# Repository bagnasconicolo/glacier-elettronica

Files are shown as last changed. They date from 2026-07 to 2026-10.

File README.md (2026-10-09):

# glacier-elettronica — Rivelatore di raggi cosmici

Front-end di lettura per un **rivelatore di muoni cosmici** basato su SiPM +
scintillatore: amplificatore veloce, discriminatore a soglia regolabile,
generazione del bias del SiPM, uscita TTL e **uscita 3,3 V per Raspberry Pi**.

Ricostruzione completa in KiCad — dal solo PDF scansionato dello schema originale
INFN sez. Torino ("Riv. Cosmici 2024 — Amplif, alim, soglie", S. Gallian) —
accompagnata da simulazioni circuitali non lineari, un verificatore che gira
**direttamente dallo schema**, la **simulazione LTspice della scheda completa** e un
sito didattico interattivo.




## Come funziona il circuito

Un muone attraversa lo scintillatore e produce un lampo di luce; il **SiPM**
(AFBR-S4N22P014M, polarizzato a ~38,4 V generati a bordo) lo converte in un
impulso di corrente. Due transistor — **BFR93A** (Q1) e **MMBTH81** (Q2) —
amplificano di ~28×. Il comparatore **MAX961** confronta con la soglia impostata
dal trimmer V2 e produce l'impulso digitale **CMP_Q**; una rete C9/R16 (latch)
evita i doppi conteggi. Da qui il segnale va al driver **MCP1402** (uscita TTL su
J2) e al buffer **74LVC1G17** alimentato a 3,3 V, che lo porta sul connettore
LEMO/J4 a 0–3,3 V, pronto per un GPIO del **Raspberry Pi**. Un timer **555** accende un LED per
11 ms a ogni evento.

Rate reale su una paletta 10×10 cm a livello del mare: **~1,7 muoni/s**.

| Schema | PCB |
|---|---|
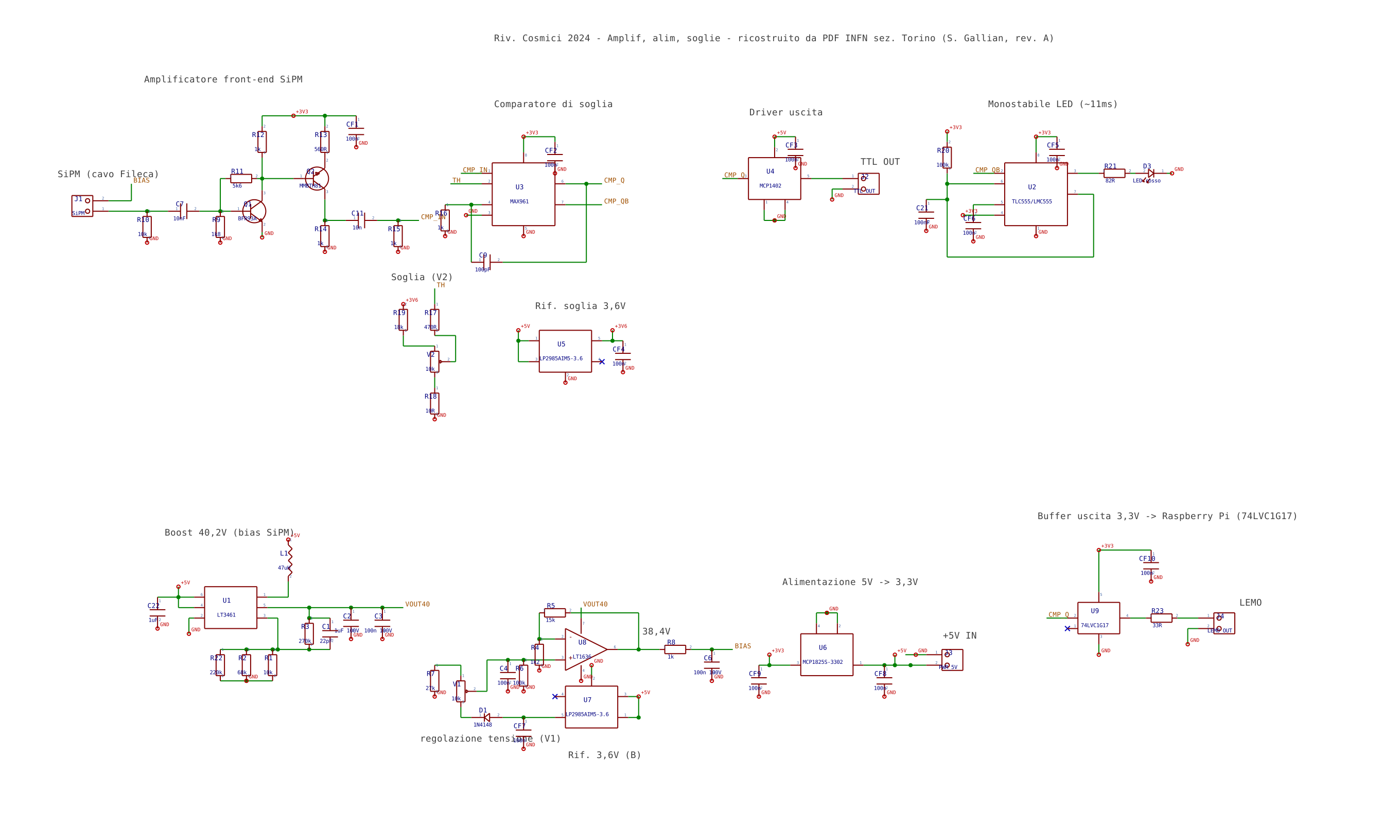
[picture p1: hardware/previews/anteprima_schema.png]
schema
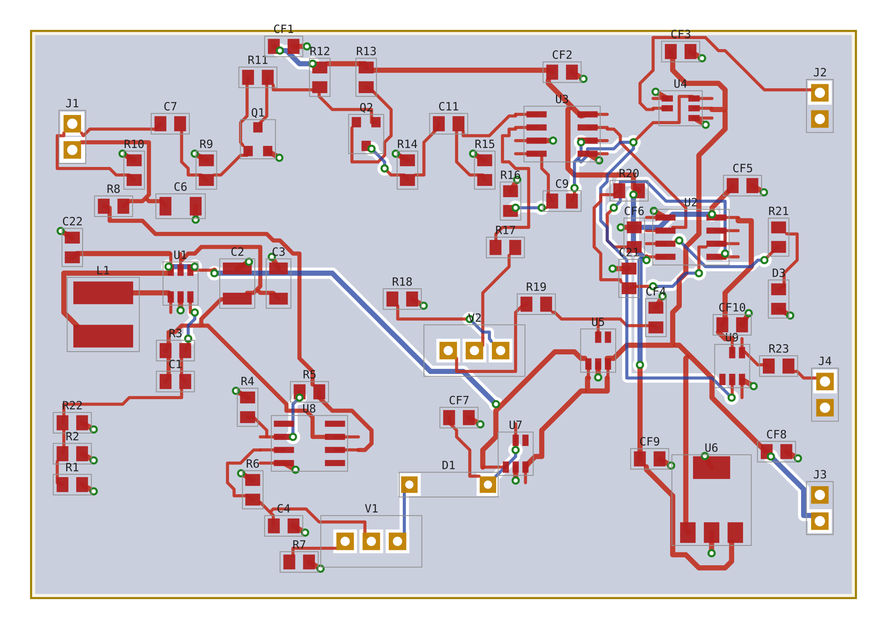
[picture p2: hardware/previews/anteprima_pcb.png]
pcb
|  |  |

## Struttura del repository

```
hardware/          progetto KiCad (schema, PCB, librerie, Gerber, BOM)
  riv_cosmici.kicad_pro/.kicad_sch/.kicad_pcb
  riv.kicad_sym, rivlib.pretty/        librerie simboli e footprint del progetto
  gerber/, riv_cosmici_gerber.zip      Gerber RS-274X + Excellon (pronti per il fab)
  bom/                                 distinta base (.xlsx e .csv) con codici Farnell/RS
  PRIMA_DI_ORDINARE.md                 cosa e' verificato e cosa decidere prima dell'ordine
  jlcpcb/                              Gerber, BOM e CPL per PCB + montaggio su JLCPCB
  variante_3ch/                        VARIANTE A 3 CANALI + coincidenza AND, uscite LEMO
  render3d/                            render 3D delle schede montate (three.js)
  previews/                            anteprime PNG
  generator/                           script Python che GENERANO lo hardware (sorgente)
simulation/        modelli circuitali non lineari + verifica dallo schema
  ltspice/             SCHEDA COMPLETA per LTspice (.asc) e ngspice (.cir) + verifica
  sim_catena.py        catena di segnale (SiPM -> ampli -> comparatore)
  sim_muoni.py         treno di muoni (Poisson + Landau) + dark count
  sim_buffer.py        (variante superata) vecchio buffer a 2 transistor
  sim_treno_completo.py (variante superata) catena fino a un Arduino a 5 V
  netlist_from_kicad.py   estrae la netlist dal .kicad_sch
  verify_from_schematic.py simula DALLA netlist estratta (front-end + uscita)
  make_recap.py        genera il PDF di recap
  riv_cosmici_frontend.cir  netlist SPICE del solo front-end (storica)
  figures/             grafici generati
web/               sito didattico interattivo (single-file, offline)
firmware/          (variante superata) sketch Arduino
docs/              schemi in PDF (1 e 3 canali), RECAP_progetto.pdf, schema_originale_INFN.pdf
```

## Due versioni

| | Scheda a 1 canale | Variante a 3 canali |
|---|---|---|
| Dove | `hardware/` | `hardware/variante_3ch/` |
| Barre / SiPM | 1 | 3 (bias e soglia regolabili per canale) |
| Uscite | LEMO/header 3,3 V + TTL 5 V | 3 LEMO 00 (canali) + 1 LEMO 00 (AND) |
| Coincidenza | — | 74LVC1G11 con jumper di esclusione |
| Test point | — | 6 per canale + 6 comuni |
| PCB | 80 × 55 mm | 103 × 215 mm, serigrafia didattica, 8 fori M3 |
| Schema PDF | `docs/schema_riv_cosmici_1canale.pdf` | `docs/schema_riv_cosmici_3canali.pdf` |

Render 3D delle schede montate: `hardware/render3d/out/1ch/` e `out/3ch/`
(rigenerabili con `python scene.py 3ch && node shoot.mjs 3ch`).

## Hardware (KiCad)

Apri `hardware/riv_cosmici.kicad_pro` con **KiCad 6 o successivo**. Le librerie di
progetto (`riv.kicad_sym`, `rivlib.pretty`) sono già referenziate da `sym-lib-table`
e `fp-lib-table` con percorso `${KIPRJMOD}`. I Gerber in `hardware/gerber/` sono
pronti per la produzione (2 layer, 80×55 mm; DRC geometrico e connettività a zero
errori). La BOM in `hardware/bom/` riporta i codici d'ordine Farnell/RS trascritti
dal progetto originale.

### Prima di ordinare

Leggi **[`hardware/PRIMA_DI_ORDINARE.md`](hardware/PRIMA_DI_ORDINARE.md)**: elenca cosa è
stato verificato (schema = originale INFN pin per pin, piedinature sui datasheet, DRC e
connettività del PCB, simulazione della scheda intera) e i punti da decidere al
montaggio, che non richiedono modifiche al PCB: R3 per restare sotto i 40 V del
LT3461, i condensatori d'uscita dei regolatori, l'ingombro di L1 e il LEMO.

Rigenerare tutto (schema, PCB, Gerber, BOM, anteprime) dal modello dati:

```bash
cd hardware/generator
python gen_sch.py && python gen_pcb.py && python gerber_out.py && python gen_bom.py
python gen_jlcpcb.py   # dopo aver aggiornato hardware/gerber e lo zip
python render_sch.py && python render_pcb.py
# schema, PCB e Gerber escono in generator/riv_cosmici/: copiarli in hardware/
```

## Simulazioni

Tutto in Python puro (nessun SPICE richiesto): un solver MNA + Newton con transistor
Ebers-Moll. Installa le dipendenze e lancia gli script da `simulation/`:

```bash
pip install -r requirements.txt
cd simulation
python sim_catena.py          # risposta della catena, punto di lavoro DC
python sim_muoni.py           # treno di muoni + dark count, reiezione
python sim_buffer.py          # buffer: CMP_Q vs TTL, storage time
python sim_treno_completo.py  # end-to-end fino al pin Arduino
```

Risultati principali (dettaglio in `simulation/RISULTATI_SIMULAZIONE.md`):
guadagno ~35 mV/fotoelettrone, saturazione oltre ~40 p.e.; soglia regolabile da
~2 mV a ~1,3 V; 7 muoni → 7 conteggi con 46 dark count rigettati; rate medio
1,68 conteggi/s a scala reale.

### Simulazione LTspice della scheda COMPLETA

In `simulation/ltspice/` c'è tutta la scheda — alimentazioni, boost 40 V, bias del SiPM,
front-end, soglia, comparatore con latch, driver TTL, 555 + LED, uscita per il
Raspberry Pi — come **schema LTspice** (`riv_cosmici_completo.asc`, si apre e si preme
Run) e come netlist (`.cir`, anche per ngspice). È generata dallo stesso modello dati
dello schema KiCad: riferimenti e nomi delle reti coincidono.

```bash
cd simulation/ltspice
python verifica_ltspice.py   # .asc == .cir, copertura KiCad, 21 controlli, grafico
```

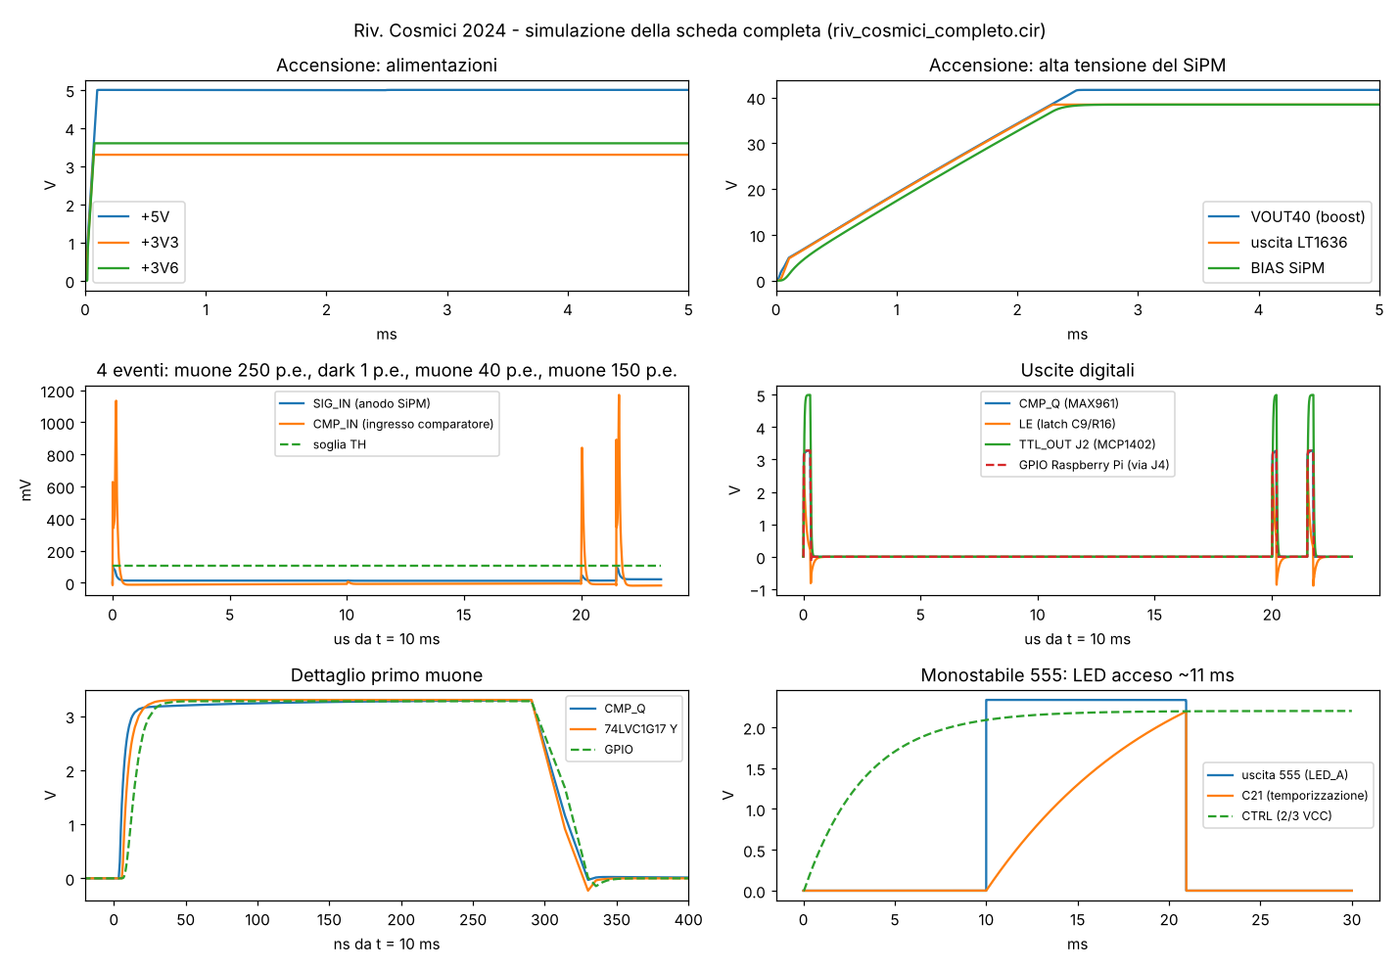
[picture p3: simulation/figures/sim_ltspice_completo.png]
simulazione completa


Dettagli, parametri e limiti dei modelli: [`simulation/ltspice/LEGGIMI.md`](simulation/ltspice/LEGGIMI.md).

### Verifica DIRETTA dallo schema

Le simulazioni normali usano una netlist trascritta a mano. Per legare la verifica
allo schema vero:

```bash
cd simulation
python verify_from_schematic.py            # front-end letto dal .kicad_sch
python verify_from_schematic.py --uscita   # + stadio d'uscita (U9 -> J4) dal .kicad_sch
```

`netlist_from_kicad.py` estrae la netlist per geometria direttamente dal file
`hardware/riv_cosmici.kicad_sch` (valori, fili, etichette, alimentazioni) e
`verify_from_schematic.py` la simula: il punto di lavoro coincide col riferimento al
millivolt, e un errore introdotto nello schema (valore o cablaggio) cambia il
risultato — così la simulazione diventa una vera verifica dello schema.

Il **PDF di recap** con tutti i grafici e i numeri si rigenera con:
`python make_recap.py` → `docs/RECAP_progetto.pdf`.

## Sito didattico

In `web/` ci sono pagine HTML autonome (funzionano offline, senza librerie
esterne), con dentro lo **stesso solver circuitale** portato in JavaScript:

- `schematico_interattivo.html` — lo schema elettrico "vivo": lancia un muone al
  rallentatore, sonde sui nodi, componenti cliccabili, trimmer della soglia
  trascinabile, oscilloscopio.
- `viaggio_del_muone.html` — la catena stadio per stadio, con i grafici ricalcolati
  in tempo reale.
- `rivelatore_cosmici.html` — cruscotto con muoni animati e conteggio.

## Lettura con Raspberry Pi

J4 pin 1 → un GPIO (es. GPIO17) con 330 Ω in serie, J4 pin 2 → GND. L'uscita è
0–3,3 V. Ogni muone dà un impulso di ≥ 84 ns: va contato **a interrupt sul fronte di
salita** (es. `libgpiod`, eventi `RISING_EDGE`), non in polling. **Non collegare J2**
(TTL a 5 V) al Pi. Lo sketch in `firmware/` è della vecchia variante Arduino a 5 V.

## Rigenerare lo hardware

Gli script in `hardware/generator/` sono il "sorgente" da cui sono stati generati
schema, PCB, Gerber e BOM (via codice, per costruzione riproducibile), tutti dallo
stesso modello dati `netdata.py`; i comandi sono nella sezione "Prima di ordinare".
Anche la simulazione LTspice (`simulation/ltspice/gen_ltspice.py`) parte da lì.

## Crediti e licenza

Progetto originale: **INFN sezione di Torino**, "Riv. Cosmici 2024 — Amplif, alim,
soglie" (S. Gallian, 2024). Ricostruzione KiCad, buffer, simulazioni, verifica e
materiale didattico: questo repository.

Rilasciato sotto **CERN Open Hardware Licence Version 2 — Weakly Reciprocal**
(CERN-OHL-W-2.0): vedi `LICENSE` e `LICENSE.CERN-OHL-W-2.0.txt`. Il software di
supporto (script Python/JS, firmware) è distribuito con lo stesso spirito.

## Monitor delle tensioni (scheda a 3 canali)

Un ADC MCP3424 sulla scheda legge i tre bias dei SiPM e l'alta tensione; il Raspberry Pi li legge in I²C con `software/monitor_tensioni.py`. Dettagli e verifica che non disturbi le misure: `hardware/variante_3ch/LEGGIMI.md` e `simulation/ltspice/verifica_monitor.py`.

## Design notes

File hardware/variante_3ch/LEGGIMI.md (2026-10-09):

# Variante a 3 canali + coincidenza

Una sola scheda (103 × 215 mm, 2 strati, 8 fori di fissaggio M3) con **tre front-end completi** del rivelatore
INFN — uno per barra di scintillatore — e la **coincidenza AND** già a bordo.
Il PCB è pensato anche per **attività didattiche (STEM)**: è diviso in blocchi
funzionali con il nome scritto in serigrafia, e i test point sono accanto ai punti che
misurano.

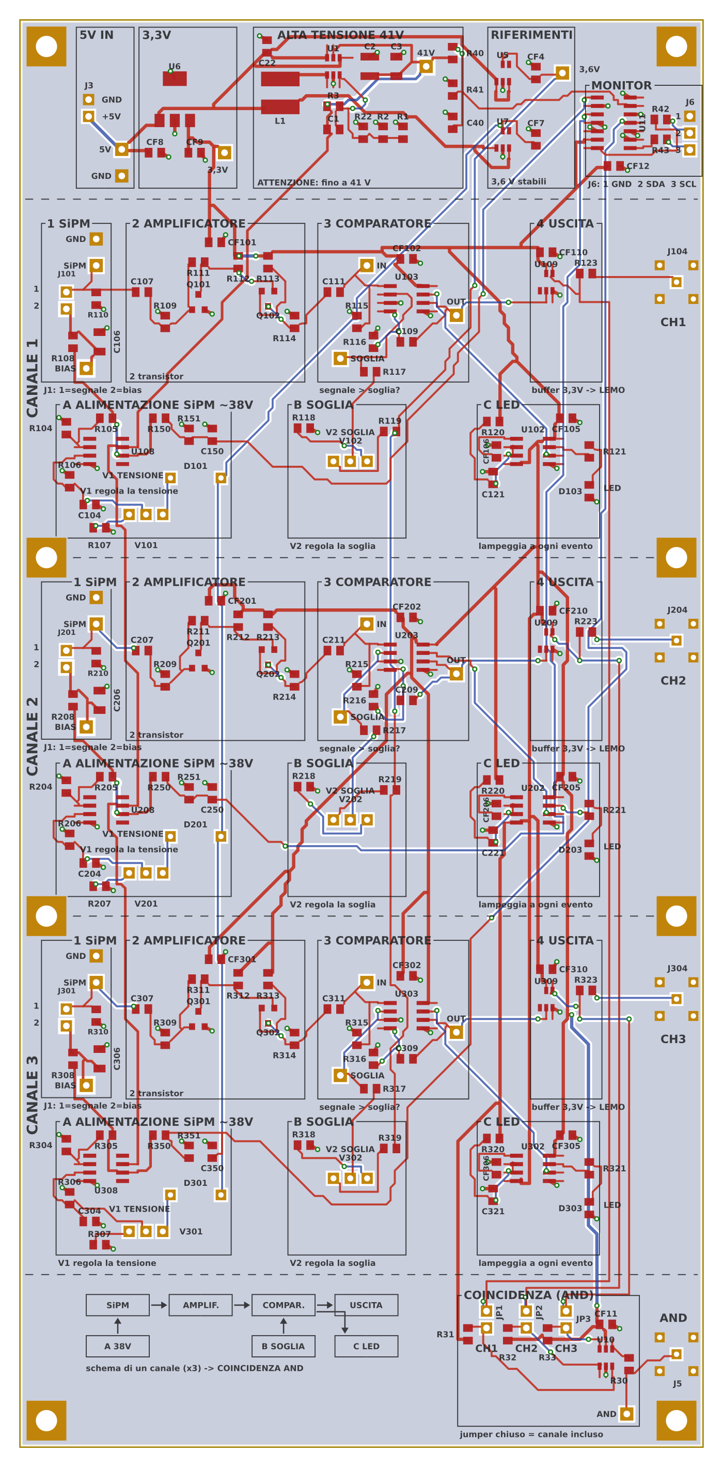
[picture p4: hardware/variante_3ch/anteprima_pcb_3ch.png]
PCB


| File | Contenuto |
|---|---|
| `riv_cosmici_3ch.kicad_pro/.kicad_sch/.kicad_pcb` | progetto KiCad (librerie in `../riv.kicad_sym`, `../rivlib.pretty`) |
| `gerber/`, `riv_cosmici_3ch_gerber.zip` | Gerber + foratura per la produzione |
| `BOM_riv_cosmici_3ch.csv` | distinta completa (anche le parti da montare a mano) |
| `jlcpcb/` | BOM e CPL per il montaggio JLCPCB (stessa procedura di `../jlcpcb/LEGGIMI.md`) |
| `../../docs/schema_riv_cosmici_3canali.pdf` | schema in PDF (A1) |
| `../render3d/out/3ch/` | render 3D della scheda montata |

Tutto è generato da `hardware/generator/` (`netdata3.py`, `gen_sch3.py`, `pcb_data3.py`,
`gen_pcb3.py`, `gen_variante3.py`) a partire dal modello della scheda a 1 canale: il
circuito di ogni canale è **identico** all'originale INFN.

## Com'è fatta (si legge dall'alto in basso)

| Fascia | Cosa c'è |
|---|---|
| **Alimentazione** (in alto) | `5V IN` (J3) → `3,3V` (U6) → `ALTA TENSIONE 41V` (U1, LT3461) → `RIFERIMENTI` 3,6 V (U5 soglie, U7 bias) → `MONITOR` (ADC delle tensioni, I²C) |
| **Canale 1, 2, 3** | riga alta = percorso del segnale da sinistra a destra: `1 SiPM` → `2 AMPLIFICATORE` → `3 COMPARATORE` → `4 USCITA` (LEMO sul bordo destro); riga bassa = circuiti di supporto sotto il blocco che servono: `A ALIMENTAZIONE SiPM ~38V` (V1), `B SOGLIA` (V2), `C LED` (555) |
| **Coincidenza** (in basso) | schema a blocchi di un canale in serigrafia; jumper JP1–JP3 → AND a 3 (U10) → LEMO J5 |
| **Lato saldature** | legenda "Come funziona" (testo specchiato, si legge girando la scheda) |

- Ogni canale ha **lo stesso piazzamento**, spostato di 54 mm: trovato un punto sul
  canale 1, è nello stesso posto sugli altri due.
- **Riferimenti**: R9 del canale 2 si chiama R209, U3 del canale 3 si chiama U303, ecc.
  Tutti i riferimenti sono stampati in serigrafia.
- Il circuito di ogni canale è **identico** all'originale INFN; tolto solo il driver TTL
  a 5 V (MCP1402, J2): le uscite sono LEMO a 3,3 V.

## Fori di fissaggio

8 fori **M3** (foro 3,2 mm metallizzato, piazzola 6 mm collegata a massa): ai quattro
angoli e sui due lati in corrispondenza del confine tra un canale e l'altro, a 4 mm dai
bordi. Per il montaggio su pannello bastano distanziali M3 da 10 mm (il trimmer più alto
è 10 mm). Le posizioni esatte sono in `hardware/generator/pcb_data3.py` (`MH_POS`) e si
possono controllare sul PDF in scala 1:1 (`stampa_1a1_riv_cosmici_3ch.pdf`).

## Uscite LEMO (bordo destro, dall'alto)

| LEMO | Segnale |
|---|---|
| J104 | canale 1 (0–3,3 V, 33 Ω in serie) |
| J204 | canale 2 |
| J304 | canale 3 |
| J5 | **coincidenza AND** dei canali inclusi (in basso) |

Footprint per **LEMO EPL.00.250.NTN** (presa a gomito da circuito stampato, serie 00):
contatto centrale + 4 piedini di schermo su quadrato 5,08 mm, fori 0,8 mm, frontale
verso l'esterno della scheda. **Prima dell'ordine, appoggia un LEMO vero sul disegno
del PCB in scala 1:1** e verifica fori e distanza dal bordo.

## Coincidenza e jumper JP1–JP3

U10 (74LVC1G11) fa l'AND delle uscite dei tre canali. Ogni ingresso passa da un jumper
(sulla scheda c'è scritto `CH1`, `CH2`, `CH3` sotto ciascuno). Le uscite dei canali
scendono alla coincidenza in un **corridoio riservato** lungo il bordo destro, senza
passare sopra i circuiti degli altri canali. I tre ingressi dell'AND sono equivalenti:
il canale 1 va al pin 3 (B), il 2 al pin 1 (A), il 3 al pin 6 (C), per avere piste
senza incroci.

| JP | Chiuso | Aperto |
|---|---|---|
| JP1 | canale 1 nella coincidenza | canale 1 escluso (ingresso tenuto a 1 da R31) |
| JP2 | canale 2 | escluso (R32) |
| JP3 | canale 3 | escluso (R33) |

Tutti chiusi = coincidenza tripla; JP3 aperto = coincidenza doppia 1·2, e così via.
Impulsi dei canali ≥ 84 ns (latch del MAX961): per muoni che attraversano le tre
barre i fronti arrivano entro pochi ns e gli impulsi si sovrappongono.

## Test point per oscilloscopio

Ogni test point ha il nome stampato accanto ed è **a pochi mm dal nodo che misura**:
le piste che li collegano sono corte e non fanno da antenna (nella versione precedente
i test point erano in colonna sul bordo e aggiungevano fino a 7 cm di pista
sull'ingresso dell'amplificatore).

| Canale n (stesse posizioni in ogni canale) | Scritta | Dove |
|---|---|---|
| TPn01 SIG_IN (anodo SiPM) | `SiPM` | accanto a J1 |
| TPn06 GND | `GND` | sopra TPn01: molla di massa della sonda |
| TPn05 BIAS (~38 V: attenzione) | `BIAS` | sotto il filtro R8/C6 |
| TPn02 CMP_IN (ingresso comparatore) | `IN` | accanto a U3 |
| TPn03 TH (soglia) | `SOGLIA` | accanto a R17 |
| TPn04 CMP_Q (uscita comparatore) | `OUT` | tra U3 e il buffer |

| Comuni | Scritta |
|---|---|
| TP1 VOUT40 (~41 V) | `41V` |
| TP2 +5V, TP6 GND | `5V`, `GND` (accanto a J3) |
| TP3 +3V3 | `3,3V` |
| TP4 +3V6 | `3,6V` |
| TP5 uscita AND | `AND` |

Fori da 1 mm: ci va un **pin di strip header** (tagliato dalla stessa strip 1×40 dei
connettori, costa quasi niente) oppure un anello Keystone 5000 (rosso) / 5001 (nero, GND).
Usa una sonda 10× con la molla di massa corta sul GND più vicino.

## Monitor delle tensioni (blocco `MONITOR`)

Un ADC **MCP3424** (U11, I²C, indirizzo 0x68) legge quattro tensioni e le passa al
Raspberry Pi dal connettore **J6** (1 GND, 2 SDA, 3 SCL; le pull-up sono quelle del Pi):

| Ingresso ADC | Cosa misura | Partitore |
|---|---|---|
| CH1, CH2, CH3 | uscita del regolatore del bias (VREG38) dei canali 1, 2, 3 | R150/R151, R250/R251, R350/R351 (1 MΩ / 43 kΩ) + C?50 100 nF |
| CH4 | alta tensione (41 V) | R40/R41 (1 MΩ / 43 kΩ) + C40 100 nF |

Lettura: `software/monitor_tensioni.py` (stampa e salva in CSV una volta al secondo).
Risoluzione a 16 bit: 62,5 µV all'ADC = **1,5 mV sul bias**. Con resistenze all'1 % la
lettura assoluta va tarata una volta col multimetro sul test point BIAS (fattore `CAL`
nello script); dopo, si vedono bene anche le variazioni del bias con la temperatura
(~28 mV/°C, la compensazione del diodo D1).

### Perché non disturba le misure

- **Si misura VREG38, non BIAS.** VREG38 è l'uscita dell'op-amp U?08, dentro il suo
  anello di retroazione (R5/R4): i 37 µA del partitore non ne cambiano la tensione, e
  quindi nemmeno quella del SiPM. Tra il partitore e il SiPM resta il filtro R8/C6.
- **Nessun disturbo verso il SiPM.** Il partitore è da 1 MΩ e il punto di misura ha
  100 nF verso massa: gli impulsi di campionamento dell'ADC finiscono nel condensatore,
  e quello che risale fino a VREG38 è attenuato di oltre un milione di volte, prima
  ancora del filtro R8/C6.
- **Le piste verso l'ADC sono "ferme".** Portano una tensione continua di ~1,6 V con
  100 nF all'estremo del canale: non fanno da antenna.
- **Il digitale è lontano e lento.** ADC e connettore sono nella fascia alimentazione,
  lontani dagli amplificatori; le resistenze da 100 Ω in serie su SDA/SCL addolciscono i
  fronti. L'ADC lavora "one-shot": converte solo quando il Pi glielo chiede (una volta
  al secondo) e per il resto è fermo.
- **Carico trascurabile.** 4 × 37 µA in più sull'alta tensione (il survoltore ne dà
  qualche mA).
- **In caso di guasto** (alta tensione a 45 V) all'ADC arrivano 1,86 V, sotto il suo
  fondo scala di 2,048 V e lontano dal limite di alimentazione.

**Non misuriamo la corrente del SiPM.** Si potrebbe ricavare dalla caduta su R8 (1 kΩ),
ma con 0,1–1 µA di corrente di buio sono 0,1–1 mV su 38 V: l'errore dei partitori (1 %
di 38 V = 380 mV) la coprirebbe del tutto. Servirebbe un amplificatore dedicato vicino al
SiPM, cioè proprio sul nodo più delicato: non ne vale la pena.

## Montaggio

JLCPCB monta 147 componenti (`jlcpcb/`). **A mano** (non in BOM/CPL):

| Rif. | Parte | Per scheda |
|---|---|---|
| U1 | LT3461 | 1 |
| U103, U203, U303 | MAX961 | 3 |
| U108, U208, U308 | LT1636 | 3 |
| U5, U7 | LP2985AIM5-3.6 | 2 |
| D101, D201, D301 | 1N4148 | 3 |
| J101, J201, J301 | Molex KK 254 22-27-2021 (cavo barra: 22-01-3027 + 2× 08-50-0114; pin 1 = centrale/segnale, pin 2 = calza/bias) | 3 |
| J3 | header 1×2 (5 V) | 1 |
| J6 | header 1×3 (I²C verso il Raspberry Pi) | 1 |
| JP1–JP3 | header 1×2 + ponticello | 3 |
| J104, J204, J304, J5 | LEMO EPL.00.250.NTN | 4 |
| TP* | test point (pin di strip header) | 24 |

Ordine Farnell per 5 schede (con scorta): `ordine_farnell.csv`.

Prima accensione: come per la scheda singola (`../PRIMA_DI_ORDINARE.md`), un canale
alla volta: alimentazioni → U1 → per ogni canale U?08 (regola il bias **senza SiPM**)
→ U?03 (regola la soglia) → SiPM. Per i punti da decidere (R3 = 255k, 2,2 µF su CF4,
CF7, CF9) valgono le stesse note della scheda singola.

## Verifiche fatte

- Schema: netlist riletta dal `.kicad_sch` per geometria = modello dati (0 differenze).
- PCB: autorouter + DRC geometrico + connettività: **0 errori**.
- Piste corte e uguali nei tre canali (mm): ingresso SiPM 9, ingresso comparatore 18,
  soglia 16–24, bias 9–11, uscita comparatore 26–28.
- Serigrafia: testo alto almeno 0,9 mm (tratto ~0,17 mm), mai sopra i pad; generata da
  `silk3.py` e identica in KiCad (`gr_poly`) e nei Gerber.
- Non ancora fatto: simulazione SPICE della scheda a 3 canali (il canale è identico a
  quello simulato in `simulation/ltspice/`); ERC/DRC ufficiali in KiCad.

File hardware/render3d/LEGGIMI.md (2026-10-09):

# Render 3D della scheda montata

## Aprirlo nel browser

Serve solo un server web statico (il browser non carica i file da `file://`).
Dalla cartella `hardware/render3d`:

```
python3 -m http.server 8000
```

poi apri nel browser:

| Indirizzo | Cosa mostra |
|---|---|
| http://localhost:8000/viewer.html?v=3ch | scheda a 3 canali, maschera verde |
| http://localhost:8000/viewer.html?v=3ch&pcb=nero | maschera nera |
| http://localhost:8000/viewer.html?v=1ch | scheda a 1 canale |

Mouse: tasto sinistro ruota, rotella zoom, tasto destro sposta.
Altri parametri: `&view=iso|top|ch1|tp|tp2|coinc|lemo` (inquadrature pronte),
`&bg=1a1f27` (colore dello sfondo).

three.js arriva dal CDN jsDelivr, quindi serve la connessione a internet.
Su Windows, se `python3` non c'è, usa `py -m http.server 8000`.

## Rigenerare la scena e le immagini

```
python3 scene.py 3ch          # out/3ch/scene.json + top.png (dopo modifiche al PCB)
python3 scene.py 3ch nero     # texture con maschera nera
npm install                   # three + playwright-core (solo per le immagini)
node shoot.mjs 3ch iso top    # PNG in out/3ch/ (Chromium headless)
PCB=nero node shoot.mjs 3ch iso
```

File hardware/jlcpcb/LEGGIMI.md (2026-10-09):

# Ordine su JLCPCB — PCB + montaggio

Tre file da caricare su [jlcpcb.com](https://jlcpcb.com) → *Order now*:

| File | A cosa serve |
|---|---|
| `riv_cosmici_gerber.zip` | Gerber + foratura: il circuito stampato |
| `BOM_JLCPCB.xlsx` (o `.csv`) | distinta dei componenti da montare (33 righe, 53 componenti) |
| `CPL_JLCPCB.xlsx` (o `.csv`) | posizione e rotazione di ogni componente |
| `MPN_riferimento.csv` | solo per te: il codice del produttore delle righe da controllare |

Generati da `hardware/generator/gen_jlcpcb.py` (stesso modello dati di schema e PCB).

**Non montati da JLCPCB (DNP), da saldare a mano** (non sono nella BOM né nel CPL; le
piazzole restano sulla scheda):

| Rif. | Parte | Perché a mano |
|---|---|---|
| U1, U3, U8 | LT3461, MAX961, LT1636 | costosi / poco disponibili: si comprano a listino |
| U5, U7 | LP2985AIM5-3.6 (SOT-23-5) | esauriti a JLCPCB al 9/10/2026 |
| D1 | 1N4148 (DO-35, foro passante) | esaurito a JLCPCB al 9/10/2026 |
| J1–J4 | header 1×2 passo 2,54 mm (o fili) | non riconosciuti dal BOM Tool |

Nella BOM ogni riga ha il **JLCPCB Part #** oppure, come Comment, il **codice del
produttore** (i resistori sono UNI-ROYAL `0805W8F…T5E`, la serie standard di JLCPCB):
così il BOM Tool trova il pezzo esatto invece di indovinarlo dalla descrizione.

## 1. Opzioni del PCB

| Opzione | Valore |
|---|---|
| Base material | FR-4 |
| Layers | 2 |
| Dimensions | 80 × 55 mm (le legge dal Gerber) |
| PCB Qty | 10 |
| PCB Thickness | 1.6 mm |
| PCB Color | a scelta (verde = più economico) |
| Surface Finish | HASL lead-free (o ENIG) |
| Outer Copper Weight | 1 oz |
| Via covering | Tented |
| Min via hole / diameter | 0.4 / 0.8 mm (rientra nello standard) |
| Mark on PCB | Remove mark (opzionale, costa poco) |
| Il resto | default |

Regole del progetto: piste ≥ 0,3 mm, isolamento ≥ 0,22 mm (0,4 mm attorno alle reti a
40 V), fori ≥ 0,4 mm: tutto dentro le capacità standard di JLCPCB.

## 2. Montaggio: dove si caricano BOM e CPL

Il prezzo che compare dopo il Gerber (~$11) è **solo il PCB nudo**. Il montaggio si
aggiunge così:

1. Nella stessa pagina scorri in fondo fino a **PCB Assembly** e attivalo.
2. Imposta: PCBA Type **Economic** (se segnala i componenti a foro passante, passa a
   **Standard**), Assembly Side **Top Side**, PCBA Qty **10**, Tooling holes
   **Added by JLCPCB**, Confirm Parts Placement **Yes**.
3. Premi **NEXT** (a destra): appare l'anteprima del PCB → di nuovo **NEXT**.
4. Solo adesso compaiono i due pulsanti **Add BOM File** e **Add CPL File**: carica
   `BOM_JLCPCB.xlsx` e `CPL_JLCPCB.xlsx` (vanno bene anche i `.csv`) → **Process BOM & CPL**.
5. Pagina dei componenti (controlli al punto 3) → **NEXT** → anteprima del piazzamento →
   **NEXT** → il prezzo totale con il montaggio.

Se un caricamento dà errore, annota il messaggio esatto: di solito indica la colonna
o la riga che non va.

## 3. Controlli nella pagina dei componenti

- Tutte le righe dovrebbero risultare abbinate. Se un resistore resta "No matches" o
  "Unconfirmed", cerca nel loro catalogo il valore in 0805 1% e scegli una parte
  **Basic** (costa meno: niente tassa per parti fuori libreria).
- Se una parte risulta **senza stock** ("0 JLCPCB"), sceglila in alternativa con stesso
  valore e package, oppure toglila e aggiungila alla lista da saldare a mano.
- **Rotazioni**: nell'anteprima controlla il **pin 1** di U2, U4, U6, U9 e l'orientamento
  di Q1, Q2 e D3 (catodo = lato con la barra sul silkscreen). Le convenzioni di rotazione
  cambiano tra programmi: se un componente è girato, correggilo lì (90°/180°).
- **PCBA Qty**: nel tuo primo tentativo risultava 15. Mettila a 10 (o al minimo che
  accettano) se non ti servono schede in più.

## 4. Varianti consigliate (vedi `hardware/PRIMA_DI_ORDINARE.md`)

Stesso PCB, cambia solo la BOM:

| Rif. | Valore INFN | Consigliato | Perché |
|---|---|---|---|
| R3 | 270k | **255k 1%** | boost a 39,4 V invece di 41,7 V (max assoluto LT3461: 40 V) |
| CF4, CF7, CF9 | 100 nF | **2,2 µF X7R 0805 ≥10 V** | uscita LP2985 ≥ 2,2 µF, MCP1825 ≥ 1 µF da datasheet |

Se le adotti, modifica le righe nel CSV prima di caricarlo (CF4, CF7, CF9 diventano
una riga separata).

## 5. Da comprare a parte (Mouser / Farnell / DigiKey)

| Rif. | Parte | Qta (con scorta) |
|---|---|---|
| U1 | LT3461ES6#TRMPBF (SOT-23-6) | 12 |
| U3 | MAX961ESA+ (SOIC-8) | 12 |
| U8 | LT1636CS8#PBF (SOIC-8) | 12 |
| U5, U7 | LP2985AIM5-3.6/NOPB (SOT-23-5) | 24 |
| D1 | 1N4148 DO-35 | 12 |
| J1–J4 | pin header maschio 1×2 passo 2,54 mm (o una strip da tagliare) | 45 |
| — | SiPM Broadcom AFBR-S4N22P014M (Farnell 4351470) | 10 |

## 6. Prima accensione

Prima salda J1–J4, U5, U7 e D1 (servono alle alimentazioni e ai riferimenti), poi i tre
chip uno alla volta, controllando le tensioni passo per passo; la sequenza è in
`hardware/PRIMA_DI_ORDINARE.md`. In breve: 5 V → 3,3/3,6 V → U1 (VOUT40) → U8, regola
V1 a 38,4 V **senza SiPM** → U3, regola la soglia con V2 → collega il SiPM.

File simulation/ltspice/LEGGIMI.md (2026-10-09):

# Simulazione LTspice della scheda completa

Tutta la scheda — alimentazioni, boost, bias del SiPM, front-end, soglia, comparatore,
driver TTL, monostabile LED, uscita per Raspberry Pi — in un solo schema simulabile.

| File | Cosa contiene |
|---|---|
| `riv_cosmici_completo.asc` | **schema LTspice** (aprilo e premi Run) |
| `riv_*.asy` | simboli usati dallo schema (devono stare nella stessa cartella) |
| `riv_cosmici_completo.cir` | stessa scheda come netlist (LTspice o ngspice) |
| `riv_cosmici_modelli.lib` | modelli: transistor, diodi, SiPM, trimmer e tutti gli integrati |
| `gen_ltspice.py` | genera `.asc`, `.asy` e `.cir` da `hardware/generator/netdata.py` |
| `verifica_ltspice.py` | rilegge l'`.asc`, lo confronta con la `.cir`, simula e controlla |
| `ngspice_run.py` | esegue ngspice e legge le forme d'onda (usato dalla verifica) |

**Lo schema è generato dallo stesso modello dati del KiCad**: riferimenti (R1, U3, …) e
nomi delle reti (CMP_IN, BIAS, …) sono identici. Nell'`.asc` i componenti sono raggruppati
per blocco funzionale; ogni pin ha un'etichetta col nome della rete, e due pin con la
stessa etichetta sono collegati (come le label di KiCad). GND = `0`, +5V = `V5`,
+3V3 = `V3V3`, +3V6 = `V3V6`.

## Uso con LTspice

1. Copia tutta la cartella `simulation/ltspice/` (servono `.asc`, tutti i `.asy` e
   `riv_cosmici_modelli.lib`).
2. Apri `riv_cosmici_completo.asc` e premi **Run**. Il transitorio dura 30 ms; con i
   modelli comportamentali impiega pochi secondi.
3. Sonde utili: `V(BIAS)`, `V(VOUT40)`, `V(CMP_IN)` con `V(TH)`, `V(CMP_Q)`, `V(LE)`,
   `V(TTL_OUT)`, `V(RPI_GPIO)`, `V(LED_A)`.
4. I risultati delle misure `.meas` sono in **View → SPICE Error Log**.

Parametri principali (direttive `.param` in fondo allo schema):

| Parametro | Significato | Default |
|---|---|---|
| `V1_POS` | posizione del trimmer V1 (bias SiPM) | 0,76 → 38,4 V |
| `V2_POS` | posizione del trimmer V2 (soglia) | 0,92 → ~104 mV (~7 p.e.) |
| `VBD`, `G12`, `VOV` | SiPM AFBR-S4N22P014M: breakdown, guadagno a 12 V OV, sovratensione | 32,5 V, 7,3·10⁶, 5,94 V |
| `QPE` | carica per fotoelettrone = q·G12·VOV/12 | ~0,58 pC |
| `CSIPM`, `TAUSIPM` | capacità terminale e recharge del SiPM | 160 pF, 55 ns |
| `T_EVn`, `NPE_EVn` | istante e fotoelettroni dei 4 eventi | muone 250, dark 1, muone 40, muone 150 p.e. |

## Cosa si vede

simulazione completa

- **Accensione**: +5V in 100 µs; +3V3 e +3V6 subito dopo; il boost carica VOUT40 a
  41,65 V in ~2,4 ms e l'LT1636 porta BIAS a 38,44 V.
- **Muone 250 p.e.**: ~1,13 V all'ingresso del comparatore (saturato), CMP_Q 3,3 V per
  300 ns, TTL 5 V su J2, 3,27 V sul GPIO del Pi con 8 ns di ritardo.
- **Dark count 1 p.e.**: ~10 mV, sotto soglia → nessun impulso.
- **Muone 40 p.e.** e **muone 150 p.e. a 1,5 µs**: due impulsi distinti.
- **LED**: acceso 10,9 ms dal 555 (T = 1,1·R20·C21).

Il SiPM simulato è il Broadcom **AFBR-S4N22P014M** (2×2 mm, 2464 celle, Farnell
4351470), con i valori del datasheet. Per la temperatura usa `.options temp=…` (o
`.temp` in LTspice): la compensazione di D1 tiene la sovratensione a 5,85–5,94 V da
−10 a +50 °C.

## Verifica automatica (ngspice)

```bash
python gen_ltspice.py        # rigenera dopo una modifica a netdata.py
python verifica_ltspice.py   # 1) .asc == .cir  2) tutti i componenti KiCad presenti
                             # 3) 21 controlli numerici PASS/FAIL  4) grafico
```

## Limiti dei modelli (onestamente)

- **Integrati comportamentali** (macromodelli scritti a partire dai datasheet: soglie,
  ritardi, isteresi, limiti di corrente, rail), non i modelli dei produttori. Gli
  utenti LTspice possono sostituire LT3461 e LT1636 con i modelli Analog Devices inclusi
  in LTspice.
- **LT3461 mediato**: regola correttamente la tensione e preleva la potenza dai 5 V
  attraverso L1, ma non simula la commutazione a 1,3 MHz (ripple). Serve per i livelli
  e per la sequenza di accensione, non per il rumore del boost.
- **Stabilità dei LDO** non modellata (vedi `hardware/PRIMA_DI_ORDINARE.md` sui
  condensatori d'uscita).
- I regolatori comportamentali non hanno deriva termica: nelle simulazioni in
  temperatura varia solo ciò che dipende da diodi e transistor (D1, Q1, Q2…).
- Transistor del front-end con parametri tipici (±30% sul guadagno reale); il cavo
  Fileca non è modellato.

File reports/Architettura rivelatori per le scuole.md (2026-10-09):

# Progettare un rivelatore di muoni da vendere alle scuole

Il rivelatore va costruito come prodotto finito attorno a quattro scelte. La prima è un **ingresso unico a 12 V con una scheda di interfaccia** (protezioni, buck per il Pi, ramo pulito per il front-end, contatore di tempo su microcontrollore) che isoli il bias dei SiPM dal rumore del Raspberry Pi. La seconda è un **oggetto a vista**. Le barre sono già a tenuta di luce singolarmente, quindi restano visibili su un telaio aperto o in una teca di PMMA. Alluminio e vani chiusi servono solo a proteggere l'elettronica e il Pi, che sta in un vano separato e ventilato. Il front-end va tenuto a 10-30 cm dall'uscita dei cavi delle barre, oppure il segnale va amplificato vicino alla barra. La terza è una **piattaforma che usa solo connessioni in uscita sulla porta 443**, con buffer locale, upload HTTPS a lotti, MQTT per lo stato e isolamento per scuola imposto nel database. La quarta è una **flotta gestita con root in sola lettura, pacchetti firmati e due canali di accesso remoto indipendenti**. Il Wi-Fi integrato non è un dettaglio: porta il prodotto sotto la Direttiva Radio (RED) e, dal 1° agosto 2025, sotto i requisiti di cybersecurity delle norme EN 18031. Questi requisiti dettano anche come vanno gestiti password e aggiornamenti ([TÜV SÜD](https://www.tuvsud.com/en/knowledge-hub/technical-updates/consumer-products-and-retail-essentials/european-commission-to-extend-application-of-red-cybersecurity-requ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)). Per i conteggi e le coincidenze dentro una scuola bastano la coincidenza hardware AND e l'NTP. Il GPS con PPS diventa indispensabile solo per correlare scuole diverse, dove servono errori dell'ordine del µs o meno, mentre su Wi-Fi l'NTP sbaglia di millisecondi ([time-nuts](https://www.febo.com/pipermail/time-nuts/2017-January/103352.html)). La raccomandazione è di predisporre il GPS nell'hardware fin dal prototipo e montarlo solo dove serve. Il percorso consigliato va da 3-5 prototipi a un pilota in 2-3 scuole, e alla certificazione completa solo dopo che il pilota ha validato rete, termica e robustezza di barre e cavi in classe. I costi orientativi (stime da verificare) sono qualche centinaio di euro di materiali per unità oltre a SiPM e scintillatori, circa 5-15 k€ una tantum per la conformità e circa 1.500-2.500 € l'anno di servizi per 100 rivelatori.

## Come leggere i numeri di questo report

Tutte le note di ricerca alla base di questo documento sono state raccolte in una sessione in cui il proxy bloccava il recupero diretto di molte pagine: arxiv.org, docs.broadcom.com, raspberrypi.com, muonpi.org e pos.sissa.it. Molti fatti vengono quindi da **estratti dei motori di ricerca** delle fonti primarie citate, non dalla lettura integrale dei PDF. Nel testo una cifra accompagnata da un link è riportata dalla fonte, ma va ricontrollata sull'originale prima di entrare in una specifica o in un fascicolo tecnico. Le cifre marcate **(stima)** sono calcoli o ordini di grandezza del gruppo di ricerca e non hanno una fonte diretta. I prezzi in particolare vanno sempre riverificati: diversi listini (Mender, balena, Hetzner) erano in conflitto tra fonti diverse. Le scelte progettuali proposte, come la scheda di interfaccia o il telaio a vista con vani separati, sono raccomandazioni ragionate a partire dai casi reali, non soluzioni già validate sul campo. In fondo al report c'è una tabella dei punti aperti.

## Un ingresso a 12 V e una scheda di interfaccia proteggono il bias dei SiPM

### Perché il problema è il rumore, non il ripple in sé

Il calcolo di sensibilità ridimensiona il rischio del ripple. Per la famiglia Broadcom NUV-MT la tensione di breakdown è di circa 32,5 V, con un coefficiente termico di circa **30 mV/°C** ([Farnell, AFBR-S4N22P014M](https://be.farnell.com/broadcom/afbr-s4n22p014m/silicon-photomultiplier-1-ch-420nm/dp/4351470); [datasheet Broadcom DS103](https://www.mouser.lt/datasheet/2/678/AFBR_S4N22P014M_DS103-3367010.pdf)). Una caratterizzazione indipendente del 2026 su un dispositivo con la stessa microcella conferma il valore ([arXiv:2608.19156](https://arxiv.org/pdf/2608.19156)). Polarizzando a 38,4 V l'overvoltage è di circa 5,9 V. Poiché il guadagno è lineare nell'overvoltage, 10 mV di ripple valgono circa lo 0,17% di guadagno, mentre 1 °C senza compensazione vale circa lo 0,5% **(stima)**. Tra 15 e 30 °C, l'escursione tipica di un'aula, il guadagno senza compensazione si sposterebbe di circa il 7-8% **(stima)**. Con una soglia fissa sui MAX961 questo cambia l'efficienza. La compensazione di temperatura già presente nel progetto è quindi la scelta giusta. La letteratura mostra che la compensazione riduce la deriva di guadagno da circa 2,8%/°C a 0,3%/°C sugli MPPC Hamamatsu ([arXiv:1606.03727](https://arxiv.org/pdf/1606.03727)).

C'è però una trappola. Il sensore di compensazione deve seguire la temperatura **dei SiPM**, non quella della scheda. Se il diodo di compensazione sta sul PCB da 103×215 mm e i SiPM stanno sulle barre, la compensazione insegue la temperatura sbagliata, e il PCB si scalda vicino al Pi e al boost. Il secondo pericolo non è il ripple medio ma lo **spike di commutazione del boost** (LT3461, circa 1,3-1,5 MHz) accoppiato capacitivamente agli ingressi dei comparatori, che genera falsi trigger **(stima, da misurare con l'oscilloscopio)**. Il progetto Cosmic Pi del CERN ha imparato la lezione sul campo: il prototipo v1 aveva un'alimentazione "troppo rumorosa per il SiPM" ([OHWR wiki](https://www.ohwr.org/projects/cosmic-pi/wiki)). Lo schema boost → filtro RC/LC → regolatore lineare → RC locale sul catodo del SiPM è quello usato anche nei progetti accademici. Un esempio è un sistema di lettura SiPM con LT3482 che ottiene un ripple simulato di qualche decina di µV con filtri RC aggiuntivi contro i transienti di commutazione ([arXiv:2501.07758](https://arxiv.org/pdf/2501.07758)).

### La raccomandazione di alimentazione

Le opzioni realistiche sono due. L'**opzione A** usa l'alimentatore ufficiale Raspberry Pi USB-C da 27 W (5,1 V / 5 A), da cui la scheda rivelatore prende i 5 V dal connettore GPIO. Costa circa 9-14 € ([Elektronicavoorjou](https://elektronicavoorjou.nl/en/product/raspberry-pi-27w-usb-c-voeding-zwart/); [Novapart](https://novapart.co/products/SC1157/power-supply-usb-c-51-v-5-a-black-eu-plug/)) ed è adatta al prototipo. È però fragile come prodotto: se la scuola usa un caricatore USB-C qualsiasi, il Pi 5 limita le porte USB a 600 mA e mostra avvisi di alimentazione insufficiente ([whitepaper Raspberry Pi RP-009856-WP](https://pip-assets.raspberrypi.com/categories/685-app-notes-guides-whitepapers/documents/RP-009856-WP-1-USB%20Power%20delivery%20on%20Raspberry%20Pi%205.pdf)). Inoltre il 5 V del Pi è la sorgente di rumore più forte del sistema.

L'**opzione B** è quella consigliata per il prodotto finito. Usa un alimentatore da muro a 12 V certificato, per esempio il Mean Well GST25E12-P1J (25 W, spina EU) a circa 12 € IVA esclusa ([Alimentatorishop](https://www.alimentatorishop.com/en/external-power-supplies/gst25e12-p1j-meanwell-power-supply-wallmount-25w-12v-input-100-240-vac)). Il 12 V entra in una **scheda di interfaccia** montata sul Pi, che genera due rami separati: un buck da 5,1 V / 5 A che alimenta il Pi dai pin 5 V del GPIO, e un secondo ramo da 5 V filtrato (ferrite, filtro π, eventualmente un LDO) per il front-end INFN. Il whitepaper ufficiale conferma che un Pi 5 alimentato così, senza negoziazione USB-PD, può dichiarare la propria capacità con `PSU_MAX_CURRENT=5000` in EEPROM o `usb_max_current_enable=1` ([whitepaper RPi](https://pip-assets.raspberrypi.com/categories/685-app-notes-guides-whitepapers/documents/RP-009856-WP-1-USB%20Power%20delivery%20on%20Raspberry%20Pi%205.pdf)). Alimentare il Pi dal GPIO però **salta il fusibile e la protezione d'ingresso del Pi**. La specifica HAT e le guide di progetto chiedono quindi che sia la scheda che lo alimenta a fornire fusibile, protezione dall'inversione di polarità e un diodo di separazione nel caso in cui siano presenti entrambe le alimentazioni ([Switch Science, spec HAT](https://trac.switch-science.com/wiki/Raspberry-HAT); [JLCPCB HAT guide](https://jlcpcb.com/blog/how-to-design-raspberry-pi-hat)). Con 12 V le cadute sui cavi non contano, i connettori sono più robusti dell'USB-C e il rumore digitale si separa alla sorgente. L'alimentatore a 24 V non porta vantaggi a meno di 15 W. Il PoE+ ha senso solo come opzione per installazioni fisse con switch PoE, che le aule raramente hanno ([The Pi Hut, Uctronics PoE+](https://thepihut.com/products/uctronics-poe-hat-for-raspberry-pi-5-with-active-cooler-802-3af-at)).

La catena d'ingresso proposta comprende un jack DC bloccante o un morsetto (mai un header a 2 pin, che permette l'inversione), un TVS SMBJ15A, un eFuse o un ideal diode e un PTC di riserva. L'eFuse TI TPS25947 integra protezione dall'inversione fino a −15 V, comportamento da ideal diode, clamp di sovratensione e limite di corrente regolabile tra 0,5 e 6 A ([TI TPS25947](https://www.ti.com/lit/pdf/slvsfc9)). Tuttavia lavora solo fino a 23 V: sul ramo a 12 V va bene, ma l'alternativa LM74700 + MOSFET va valutata. Sui segnali che escono dal contenitore servono diodi ESD. Il bias va abilitato da un GPIO solo a Pi avviato, così sale e scende in modo controllato. L'MCP3424 già presente permette al software di **invalidare i dati quando il bias esce dalla finestra**: è una funzione di qualità dati che i progetti amatoriali non hanno. Contro la corruzione della SD per mancanza di corrente, la difesa a costo zero è il root in sola lettura (vedi la sezione sulla flotta). Gli UPS a supercondensatori, come il Geekworm UPS Scap a circa 47 $ ([CNX Software](https://www.cnx-software.com/2026/10/05/geekworm-ups-scap-5v5a-a-supercapacitor-ups-hat-for-raspberry-pi-5/)), restano un'opzione da testare, non una base. Il BOM aggiuntivo di alimentazione e protezione vale circa **15-30 € per unità, alimentatore incluso (stima)**.

### Marcatura CE: con il Wi-Fi il prodotto rientra nella RED

Il fabbricante del prodotto finale è responsabile della sua conformità. Un alimentatore CE e un Raspberry Pi CE non rendono conforme l'insieme ([Teltonika, esempio di DoC](https://wiki.teltonika-networks.com/view/TSW100_CE); [Johner Institute](https://blog.johner-institute.com/regulatory-affairs/radio-equipment-directive-red/)). Poiché il progetto richiede il Wi-Fi attivo, il prodotto rientra nella **RED 2014/53/UE**, che assorbe sicurezza ed EMC. Raspberry Pi fornisce le DoC dei propri moduli: quella del CM5 elenca ETSI EN 300 328, EN 301 893, EN 301 489-1 ed EN 301 489-17 ([DoC CM5](https://pip-assets.raspberrypi.com/categories/1102-approvals/documents/RP-007496-CF-2-rpi-cm5%20EU%20Declaration%20of%20Conformity%20(DoC).pdf); [DoC Pi 5](https://www.mouser.com/catalog/additional/Raspberry_Pi_rpi_5_EU_Declaration_of_Conformity_DoC.pdf)). Offre anche test report e un servizio "Global Market Access", ricordando però che la responsabilità resta del fabbricante ([RPi compliance](https://www.raspberrypi.com/for-industry/compliance/)). La DoC del prodotto dovrà quindi coprire quattro articoli della RED: l'art. 3.1(a) sulla sicurezza, con la EN IEC 62368-1 come riferimento; l'art. 3.1(b) sull'EMC, con EN 301 489-1/-17 e **EN IEC 61326-1**; l'art. 3.2 sullo spettro radio, riusando i report Raspberry Pi se antenna e integrazione restano invariate; l'art. 3.3(d) sulla cybersecurity con la **EN 18031-1**. La EN IEC 61326-1 si applica perché copre esplicitamente gli strumenti di misura e laboratorio, anche per uso "educational", e ammette l'integrazione di un computer già conforme alle norme ITE ([DLS EMC](https://www.dlsemc.com/iec-en-61326-1)). Con l'applicazione piena delle EN 18031 basta l'autodichiarazione (Modulo A). Se si scelgono opzioni non coperte, per esempio su password o aggiornamenti, serve un Organismo Notificato ([Espressif, guida EN 18031](https://developer.espressif.com/blog/2025/04/esp32-red-da-en18031-compliance-guide/)). Questo lega la conformità all'architettura software: **niente password di default, aggiornamenti firmati e servizi di rete minimi** sono requisiti normativi, non buone pratiche facoltative.

Due altre conseguenze vanno chiarite. La 41,7 V interna è sotto i 75 V DC della soglia LVD ([TÜV SÜD LVD](https://www.tuvsud.com/en-ae/services/product-certification/ce-low-voltage-directive)) e, con ogni probabilità, sotto il limite ES1/SELV di 60 V DC. Questo secondo valore non è stato verificato sul testo della norma. Va comunque documentata nell'analisi dei rischi e non deve mai arrivare a un connettore esterno. In Italia chi immette apparecchiature elettriche con il proprio marchio deve iscriversi al **Registro nazionale AEE** prima di vendere, aderire a un sistema di finanziamento dei RAEE, riportare il numero di iscrizione nei documenti commerciali e marcare il prodotto con il bidone barrato secondo la CEI EN 50419 ([InformaImpresa](https://informaimpresa.it/item/adempimenti-per-i-produttori-di-apparecchiature-elettriche-ed-elettroniche)). Sui costi, le fonti indicano 1.500-2.500 $ al giorno di laboratorio e 3.000-8.000 $ per l'EMC di un piccolo prodotto senza radio ([electronics-lab](https://www.electronics-lab.com/forums/threads/emc-compliance-testing.27689/latest)), oppure circa 3.800 € di consulenza CE forfettaria, test esclusi ([EcoComply](https://ecocomply.ai/emc-compliance)). Con la parte radio e la cybersecurity si arriva plausibilmente a **5.000-15.000 € totali (stima)**. Una giornata di pre-compliance da 500-1.500 € (stima) durante la fase prototipale riduce il rischio di ripetere i test. I punti critici attesi sono le emissioni irradiate del Pi e del boost e l'immunità a ESD e RF, che si manifesta come falsi conteggi.

## Barre a vista su un telaio, elettronica vicina ai SiPM, Pi in un vano separato

### Le barre sono già a tenuta di luce: il contenitore deve proteggerle, non oscurarle

Ogni barra di scintillatore del progetto è **già isolata otticamente da sola**: avvolta, a tenuta di luce, con un cavo che esce e va alla scheda. Questo cambia il problema meccanico. Non serve una scatola buia attorno alle barre, e le barre possono e devono **restare visibili** nell'oggetto finito. È una scelta coerente con la pratica dei progetti reali, dove la tenuta alla luce si ottiene sempre sul singolo scintillatore. CosmicWatch avvolge scintillatore e SiPM in foglio riflettente e nastro isolante nero, con accoppiamento in gel ottico ([arXiv:1801.03029](https://arxiv.org/pdf/1801.03029)). HiSPARC usa foglio d'alluminio e telo nero da laghetto ([HiSPARC, guida di montaggio](https://www.hisparc.nl/oud/fileadmin/HiSPARC/Handleidingen/Detector_mounting_translated.pdf)). QuarkNet usa foglio d'alluminio e carta nera ([QuarkNet CRMD](https://web.quarknet.org/files/cosmics/cf_crmdassemblyinstructions-small.pdf)). In tutti questi casi la barriera principale è il rivestimento del singolo scintillatore. Il contenitore esterno aggiunge soprattutto protezione meccanica, anche se alcuni progetti, come le prime versioni di CosmicWatch, lo usavano anche come seconda barriera alla luce ([arXiv:1606.01196](https://arxiv.org/pdf/1606.01196)). Al contenitore restano quattro compiti: **tenere e proteggere le barre** senza nasconderle, **proteggere l'elettronica e il Raspberry Pi**, **gestire i cavi** dalla barra alla scheda con fermacavi e connettori robusti, e **separare termicamente il Pi dai SiPM**.

Il prezzo della visibilità è che il rivestimento delle barre diventa l'unica barriera alla luce, ed è esposto a urti, unghie, nastri che si scollano e piegature del cavo nel punto di uscita. HiSPARC avverte che "anche la più piccola fessura può rovinare le misure" ([HiSPARC](https://www.hisparc.nl/oud/fileadmin/HiSPARC/Handleidingen/Detector_mounting_translated.pdf)). Il controllo della tenuta va quindi fatto sia al collaudo di fabbrica sia periodicamente a scuola, e conviene renderlo un'attività didattica. Il test va fatto sui **singoli di ciascun canale**, non sulla coincidenza triplice che nasconde le perdite: si confronta il rate con la stanza al buio e con una lampada accesa vicino alla barra, come nella procedura QuarkNet ([Making a Dark Box Light Tight](https://new.quarknet.org/sites/default/files/Making%20a%20Dark%20box%20Light%20Tight%20-%2020171019.pdf)). Le fessure si localizzano passando una torcia lungo il rivestimento, in particolare all'uscita del cavo, con il rate reso udibile come un contatore Geiger ([McMillan, arXiv:1907.03023](https://arxiv.org/pdf/1907.03023)). Se il microcontrollore della scheda di interfaccia conta i singoli in hardware (vedi la sezione sul timing), la piattaforma può anche segnalare da sola un aumento anomalo del rate di un canale che segue l'illuminazione dell'aula, cioè un rivestimento danneggiato. Una differenza del rate tra luce accesa e spenta oltre l'errore statistico va trattata come guasto. La riparazione standard è nastro nero sul punto di perdita e un nuovo test.

### Il cavo della barra: corto, bloccato, oppure con il segnale già amplificato

Il cavo che esce da ogni barra trasporta il segnale analogico del SiPM e il bias. La sua lunghezza è quindi un parametro di progetto, non un dettaglio di montaggio. Il segnale di un SiPM da 2×2 mm è piccolo, e i sistemi che lo trasmettono grezzo su metri di cavo accettano prestazioni peggiori o usano tecniche speciali. Il prototipo IFR di Fermilab giudicava "non ottimali" 4 m di coassiale ([arXiv:1306.5655](https://arxiv.org/pdf/1306.5655)). In GERDA circa 20 m di cavo riducevano molto l'ampiezza ([arXiv:1711.01452](https://arxiv.org/pdf/1711.01452)). CAEN qualifica i propri cavi di "remoting" per SiPM solo fino a 1 m ([CAEN](https://caen.it/?p=52173)). Cosmic Pi ha eliminato del tutto il problema mettendo i SiPM su una sezione staccabile del PCB principale ([OHWR wiki](https://www.ohwr.org/projects/cosmic-pi/wiki)). Al contrario, i cavi da 15 m di QuarkNet funzionano perché trasportano impulsi di fotomoltiplicatore molto più grandi ([FNAL QuarkNet](https://quarknet.fnal.gov/toolkits/ati/fnaldet.html)).

La raccomandazione **(proposta di progetto)** ha due varianti. Nella **variante base** si mantiene l'architettura attuale, con amplificazione e comparatori sul PCB INFN. Il PCB va montato a ridosso dell'estremità delle barre da cui escono i cavi, in modo che ciascun cavo resti tra **10 e 30 cm**. Il cavo deve essere un micro-coassiale schermato da 50 Ω (RG174, RG316 o un pigtail U.FL/MMCX), con il bias su un conduttore separato o nella schermatura, e con un filtro RC sul bias vicino al SiPM. Va evitato il cavo piatto non schermato, che raccoglie il rumore del Pi e del boost. Prima di congelare il progetto conviene misurare ampiezza e tempo di salita in funzione della lunghezza del cavo, come ha fatto MEG ([arXiv:1801.04688](https://arxiv.org/pdf/1801.04688)). Nella **variante con barre distanti**, se per ragioni estetiche o didattiche le barre devono stare a più di 0,5-1 m dall'elettronica (per esempio per variarne la distanza o l'angolo), conviene spostare un piccolo amplificatore, e idealmente anche il comparatore, su un carrier vicino alla barra. Il cavo trasporta allora un segnale grande o già digitale (CMOS o LVDS su doppino), e la lunghezza smette di essere critica. È quello che fa CosmicWatch v3X per il collegamento di coincidenza su cavo di rete ([arXiv:2508.12111](https://arxiv.org/html/2508.12111v2)), ed è l'approccio di un beam monitor che amplifica il segnale dell'MPPC e lo converte in LVDS prima di trasmetterlo ([arXiv:2405.17904](https://arxiv.org/pdf/2405.17904)).

In entrambe le varianti il collegamento barra-scheda deve resistere agli studenti. L'esperienza QuarkNet indica nei connettori e nei cavi il punto debole in classe: una squadra di docenti ha raccolto dati distorti per un connettore BNC staccato ([Iowa QuarkNet 2017](https://new.quarknet.org/sites/default/files/Iowa%20Quarknet%202017%20Cosmic%20Ray%20Detector%20Writeup.docx)). Servono quindi tre accorgimenti: un **fermacavo vicino all'uscita del cavo dalla barra**, perché la trazione su quel punto rompe insieme il rivestimento ottico e la saldatura; un **secondo fermacavo prima della scheda**; un **connettore con blocco** sul lato scheda (micro-coassiale con ritenuta, o un connettore a vite o push-pull) che non si possa staccare o invertire per errore. I canali vanno marcati con colori o numeri. Le uscite LEMO 00 restano riservate ai segnali digitali verso l'utente.

### Telaio aperto, coperchio trasparente, Pi in un vano a parte

Il layout raccomandato **(proposta di progetto)** è un oggetto a vista su una base robusta. Le tre barre stanno impilate in un **telaio aperto o in una teca di PMMA trasparente**, appoggiate su culle con spessori in schiuma che impediscono movimenti durante il trasporto e assorbono gli urti, ma senza stringere il rivestimento. La teca trasparente non deve essere a tenuta di luce: protegge solo da mani e urti. Su una base o una spina dorsale in alluminio, all'estremità da cui escono i cavi, sta il vano elettronica con il PCB da 103×215 mm, coperto da una finestra in PMMA o policarbonato da 3-4 mm che rende visibile anche la scheda. Il **vano del Raspberry Pi** è separato e ventilato, all'estremità opposta o sotto la base, con le uscite LEMO e AND su un pannello frontale e alimentazione ed Ethernet sul retro. Questa combinazione richiama i casi più riusciti. CosmicWatch è partito da case stampati in 3D ed è poi passato a un **estruso di alluminio commerciale con piastre frontali in acrilico tagliate al laser da 2,5 mm**, più economico ([arXiv:1801.03029](https://arxiv.org/pdf/1801.03029); [arXiv:2508.12111](https://arxiv.org/html/2508.12111v2)). Il rivelatore portatile INSULAB (Università dell'Insubria e INFN Milano-Bicocca) ha **tre moduli scintillatori impilati in una valigetta di alluminio** e un Raspberry Pi con touch screen per il monitoraggio dal vivo, ed è stato usato anche all'aperto per misure di rate in funzione della quota e dell'angolo zenitale ([arXiv:2111.10151](https://arxiv.org/pdf/2111.10151)). EEE resta un modello di rete e di didattica, non meccanico: un telescopio MRPC con sistema a gas costa circa 50.000 € ([CERN Courier](https://cerncourier.com/a/the-eee-project-big-science-goes-to-school/)).

I materiali si dividono i ruoli. L'**alluminio** (profilati, estruso o lamiera piegata e anodizzata) fa da struttura portante e da schermo elettromagnetico attorno a front-end e Pi, che è la sorgente di rumore più forte del sistema. Il **PMMA** è ideale per la teca e le finestre: è trasparente, si taglia al laser ed è bello, ma è fragile sui fori delle viti. Il **policarbonato** è più tenace e va preferito dove l'oggetto può subire urti. La **stampa 3D** va usata per culle, fermacavi, staffe e porta-connettori, preferibilmente in un grado autoestinguente UL94 V-0 come il PC-FR o il PC/ABS FR. Va ricordato che "testato secondo la norma" spesso non equivale a una certificazione UL e che il V-0 dipende dallo spessore ([Spectrum PC/ABS FR](https://spectrumfilaments.com/en/filament/pc-abs-fr-v0/); [forum Bambu](https://forum.bambulab.com/t/filament-resistance-to-flammability-ul94-v0/82057)). Per il vano elettronica può bastare un estruso commerciale. La serie Hammond 1455 offre per esempio il 1455T2201 da 165×52×220 mm a circa 44 $ ([Newark](https://www.newark.com/hammond/1455t2201rd/pcb-box-enclosure-aluminum-red/dp/30Y9630)), ma la compatibilità del PCB da 215 mm con le guide interne va verificata sui disegni. Le dimensioni delle barre non sono note in queste note, quindi il dimensionamento del telaio resta aperto.

### Termica e aspetto didattico

I SiPM dissipano microwatt, mentre un Pi 4 o 5 dissipa circa 2,5-3 W a riposo ([Pi Dramble](https://pidramble.com/wiki/benchmarks/power-consumption)). Il Pi va quindi tenuto **lontano dalle barre e dal punto in cui escono i cavi**, in un vano con prese d'aria proprie, mentre il front-end resta vicino ai SiPM per tenere corti i cavi. Con le barre a vista e senza una scatola chiusa attorno, i SiPM seguono la temperatura dell'aula, incluso il sole diretto da una finestra. Un **sensore di temperatura I2C vicino all'uscita dei SiPM**, registrato insieme ai dati come fa Cosmic Pi ([OHWR wiki](https://www.ohwr.org/projects/cosmic-pi/wiki)), serve a correggere i dati e a capire se l'elemento di compensazione del bias segue davvero la temperatura dei SiPM. Il manuale deve sconsigliare di installare il rivelatore al sole o vicino ai termosifoni. Sul lato didattico la visibilità delle barre è già un punto di forza. Vanno aggiunti un LED per canale accanto a ciascuna barra che lampeggia a ogni colpo, un cicalino sulle coincidenze e la scheda visibile sotto la finestra con le serigrafie "bias SiPM", "amplificatore", "comparatore" e "AND". I punti di test per l'oscilloscopio vanno protetti da uno sportello. Un **telaio con perno** per ruotare la pila permette misure in funzione dell'angolo zenitale, come in INSULAB, e un telaio con distanziali regolabili permette di variare la distanza tra le barre. Viti antimanomissione sui vani elettronici, spigoli arrotondati, piedini in gomma e una maniglia completano la sicurezza per l'uso in classe. Il costo orientativo della meccanica è di **80-150 € per un telaio in profilati o estruso con teca in PMMA e parti stampate, oppure 150-300 € per una base custom anodizzata in piccola serie**. A questo si aggiungono **60-150 € tra cavi schermati, connettori con blocco, LEMO (circa 15-30 € l'uno, prezzo non verificato), fermacavi, schiume e maniglia (tutte stime)**.

## Tutto in uscita sulla porta 443: spool locale, HTTPS a lotti, MQTT per lo stato

### Lo schema che accomuna HiSPARC, MuonPi ed EEE

Le reti reali convergono su uno schema comune: buffer locale sulla stazione, upload asincrono in uscita verso un server centrale, ricostruzione e sintesi periodiche, accesso pubblico via web e API. HiSPARC è il riferimento più maturo. Ogni stazione ha un **buffer MySQL locale** da cui un processo Python carica i dati a intervalli regolari ([ICALEPCS 2013](https://accelconf.web.cern.ch/ICALEPCS2013/papers/thppc064.pdf)). Il datastore centrale riceve gli upload in coda e li scrive in HDF5 ([docs HiSPARC](https://docs.hisparc.nl/datastore/writer.html)). Ogni notte un'applicazione Django produce un riassunto degli eventi ([SAPPHiRE ESD](https://docs.hisparc.nl/sapphire/esd.html)). Il monitoraggio usa Nagios con avvisi e-mail, e la manutenzione remota passa da una VPN OpenVPN ([ICALEPCS 2013](https://accelconf.web.cern.ch/ICALEPCS2013/papers/thppc064.pdf)). MuonPi, il progetto più vicino al nostro hardware (scintillatore, SiPM e Raspberry Pi), ha un daemon systemd che pubblica in **MQTT** con autenticazione per utente e più stazioni per account ([GitHub MuonPi](https://github.com/MuonPi/muondetector)). Un servizio centrale calcola le coincidenze dal broker. EEE sincronizzava file verso il cloud OpenStack di INFN-CNAF, con monitoraggio della qualità dati quasi online ([PoS ICRC2017](https://pos.sissa.it/301/478/pdf)). Il contro-esempio è QuarkNet, dove lo studente carica i file a mano e tra le richieste di supporto compaiono gli "upload failures" ([QuarkNet 2023](https://new.quarknet.org/sites/default/files/MonthlyReport_JanFeb_2023%20%281%29.pdf)).

### Protocollo: due canali, entrambi sulla porta 443

Le reti scolastiche spesso lasciano aperte solo le porte TCP 80 e 443, e la porta MQTT/TLS 8883 rischia di essere filtrata (stima, da verificare nelle scuole pilota). La raccomandazione è quindi di usare **solo connessioni in uscita su TCP 443**, divise in due canali. Il canale dati è un **upload HTTPS a lotti, idempotente**. L'acquisizione scrive in uno spool locale (SQLite in modalità WAL o file orari compressi con checksum). Un uploader invia lotti ogni 1-5 minuti con un ID univoco e cancella un lotto solo dopo aver ricevuto un ACK con hash. Il canale di stato è **MQTT 5 su WebSocket+TLS (wss://…:443)** e trasporta heartbeat, rate, tensioni di bias e temperatura, con un Last Will che segna la stazione offline. WebSocket sulla porta 443 attraversa la maggior parte dei firewall ([Alibaba Cloud IoT](https://www.alibabacloud.com/help/doc-detail/63656.html)) e Mosquitto supporta listener WebSocket con TLS e certificati client ([DEV](https://dev.to/sheng_chen_5979882122c747/configuring-tls-in-the-mosquitto-mqtt-broker-3jnb)). Il buffering affidabile non va delegato al broker: Mosquitto tiene le code dei client offline **in RAM** e, oltre `max_queued_messages`, **scarta i nuovi messaggi** ([Cedalo](https://docs.cedalo.com/mosquitto/2.9/broker/Mosquitto%20Manual/mosquitto-persistent-queue); [Eclipse mosquitto-dev](https://www.eclipse.org/lists/mosquitto-dev/msg00755.html)). Il volume è piccolo. Con 1-2 muoni al secondo e record binari da 32-64 byte sono **3-11 MB al giorno per rivelatore**, e al massimo circa 3,5 GB al giorno non compressi per 100 rivelatori **(stima)**. La SD può quindi tenere settimane di dati in attesa di rete. Le reti con proxy che ispezionano il TLS rompono i certificati client: serve un fallback con token per dispositivo e la possibilità di configurare `HTTPS_PROXY`. Un Pi senza schermo non può superare un captive portal, quindi va chiesta alla scuola una whitelist MAC o un SSID dedicato. Per eduroam e WPA2-Enterprise NetworkManager funziona, purché si installi il certificato della CA ([UNIBS, guida eduroam](https://www.unibs.it/sites/default/files/2026-09/Guida_Eduroam_Debian_Ubuntu_EN.pdf)). Per le reti più ostili il ripiego è l'Ethernet, poi un router 4G.

### Archiviazione, dashboard e multi-tenancy

A questa scala (10-100 rivelatori) la scelta più semplice è **PostgreSQL con TimescaleDB**. Le tabelle degli eventi e dello slow control sono hypertable, gli aggregati continui calcolano il rate per minuto e per ora, e la compressione si applica dopo 7 giorni. Le fonti di confronto sono di vendor e vanno lette con cautela ([TigerData](https://www.tigerdata.com/compare/influxdb); [QuestDB](https://questdb.com/blog/comparing-influxdb-timescaledb-questdb-time-series-databases)). Accanto al database serve un **archivio grezzo immutabile**: file giornalieri per stazione in HDF5 o Parquet su object storage UE, come fa HiSPARC con l'HDF5. Per gli open data si possono fare rilasci annuali su Zenodo con DOI e licenza CC-BY.

Il punto delicato è l'isolamento tra scuole. **Grafana OSS non applica la sicurezza a livello di riga** sui datasource SQL, e le variabili delle dashboard non sono un confine di sicurezza ([community Grafana](https://community.grafana.com/t/postgresql-row-level-access-in-grafana/163838)). I permessi avanzati sui datasource sono funzioni Enterprise ([Grafana blog](https://grafana.com/blog/managing-access-in-grafana-a-single-stack-journey-with-teams-roles-and-real-world-patterns/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)). L'isolamento va quindi imposto **nel database (Row-Level Security di PostgreSQL) e nell'API**. L'architettura raccomandata ha quattro elementi: Keycloak come provider OIDC (gruppi per scuola, ruoli `teacher`, `student` e `project-admin`); una web app scuola in FastAPI o Django, con frontend leggero, grafici, export CSV e pagine didattiche, che applica il tenant dai claim del token; Grafana solo per il team di progetto e per il monitoraggio operativo; pagine pubbliche senza login con mappa (posizioni arrotondate), rate dal vivo e download. Il team vede tutto grazie al ruolo `project-admin`. Il docente vede solo le stazioni della propria scuola. Per partire più in fretta si può usare una organizzazione Grafana per scuola con un ruolo Postgres dedicato soggetto a RLS, ma con 100 scuole va automatizzata via API.

Sul fronte privacy, i dati del rivelatore non sono personali, mentre lo sono account, log e indirizzi IP ([TechGDPR](https://techgdpr.com/blog/is-an-ip-address-considered-personal-data/)). La scuola, come titolare, deve nominare il gestore della piattaforma **responsabile del trattamento ex art. 28 GDPR** con un contratto specifico ([Cybersecurity360](https://www.cybersecurity360.it/legal/privacy-dati-personali/privacy-e-didattica-a-distanza-una-buona-prassi-per-i-dpo-degli-istituti-scolastici/)). L'autorità islandese ha multato un comune per un contratto di trattamento non conforme all'art. 28(3)(a) nell'uso di Google Workspace for Education ([EDPB](https://www.edpb.europa.eu/news/icelandic-sa-the-municipality-of-reykjanesbaer-fined-eur-16590-for-the-use-of-google-workspace_it)). Per gli studenti minorenni conviene evitare account nominativi e usare account di classe gestiti dal docente. L'hosting va tenuto in UE. Ogni dispositivo deve avere una propria chiave e un certificato emesso da una CA di progetto (per esempio step-ca), con ACL MQTT per topic `stations/<id>/#` e revoca centralizzata. Il costo di hosting per 100 rivelatori è stimato in **50-130 € al mese** (una o due VPS UE, object storage e backup). I listini Hetzner 2026 sono però in conflitto tra le fonti ([Hetzner](https://docs.hetzner.cloud/whats-new); [Findstack](https://findstack.com/resources/hetzner-price-increase-2026)), e GARR Cloud o INFN Cloud potrebbero azzerare il costo diretto se il servizio è erogato dall'ateneo.

## Una flotta di cento Pi si gestisce con root in sola lettura, pacchetti firmati e due canali remoti

### Quale Raspberry Pi

La longevità garantita conta più delle prestazioni, perché il carico (interrupt GPIO, I2C, upload) è leggero. Il **Pi 4 e il CM4** sono garantiti in produzione almeno fino a gennaio 2034. Il **Pi 5** almeno fino a gennaio 2036 secondo il product brief e fino al 2038 secondo l'articolo ufficiale sulla longevità. Lo **Zero 2 W** solo fino a gennaio 2030 ([forum RPi](https://forums.raspberrypi.com/viewtopic.php?t=374010); [Raspberry Pi](https://www.raspberrypi.com/news/raspberry-pis-commitment-to-longevity-a-sustainable-advantage/)). A riposo Pi 4 e Pi 5 consumano entrambi circa 2,5-3 W, lo Zero 2 W circa 0,4-0,7 W ([Pi Dramble](https://pidramble.com/wiki/benchmarks/power-consumption); [raspberry.tips](https://raspberry.tips/en/raspberrypi-tutorials/raspberry-pi-power-consumption-update-2026-all-models-compared)). La raccomandazione è il **Raspberry Pi 5 da 2 GB come piattaforma di produzione**, per tre ragioni: la finestra di supporto più lunga, l'aggiornamento A/B nativo di Raspberry Pi Connect (configurabile su Pi 5 con boot da EEPROM, [docs Connect](https://raspberrypi.com/documentation/services/connect.html)) e l'RTC integrato. Il Pi 4 resta accettabile per i prototipi. Il Pi 5 ha i GPIO dietro il chip RP1 e pigpio con ogni probabilità non lo supporta (non verificato), quindi il software va scritto su **libgpiod v2**. Il timestamp preciso va affidato al microcontrollore della scheda di interfaccia, il che rende quasi irrilevante la latenza dei GPIO del modello scelto. Lo Zero 2 W è sconsigliato per un prodotto pluriennale (fine produzione 2030, solo 2,4 GHz, 512 MB). Il **CM5 con eMMC** su una carrier custom che integri la scheda di interfaccia è la naturale evoluzione "v2" quando i volumi lo giustificano: elimina la SD estraibile, ma richiede un PCB in più.

### Storage: il guasto da temere è la mancanza di corrente, non l'usura

Non esistono studi peer-reviewed sui tassi di guasto delle SD nei Pi installati sul campo. La causa principale di corruzione quando manca la corrente sono le modifiche in cache non ancora scritte ([forum RPi](https://forums.raspberrypi.com/viewtopic.php?t=361461)), e nelle scuole la corrente viene staccata nei weekend e d'estate. Con il **root in sola lettura** e un overlay in RAM il Pi si può spegnere in qualsiasi momento ([Core Electronics](https://core-electronics.com.au/guides/read-only-raspberry-pi/)). I dati vanno su una partizione `/data` separata, scritta a blocchi con fsync, e i log in RAM con invio remoto. Il marchio "industriale" non è una garanzia. In un test di stress continuo indipendente si sono guastate 2 schede Kingston Industrial su 3, con una media di circa 77 giorni ma sotto scrittura ininterrotta, molto lontana dai pochi MB al giorno di questo uso ([Tom's Hardware](https://www.tomshardware.com/pc-components/microsd-cards/microsd-card-testing-database-celebrates-third-anniversary-with-133-petabytes-of-data-written-across-4-6-mil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)). Un utente con molti Pi sul campo segnala guasti frequenti anche con root in sola lettura ([forum RPi](https://forums.raspberrypi.com/viewtopic.php?t=253104)). La strategia giusta combina quindi una SD pSLC industriale (circa 15-30 €, stima) come assicurazione, poche scritture e una **sostituzione rapida pianificata**: immagine standard, identità recuperabile e dati già caricati sul server.

### Aggiornamenti, accesso remoto e monitoraggio

La strategia raccomandata separa due livelli. Il **sistema operativo** si aggiorna raramente e in modo atomico A/B. Il **software di acquisizione** si aggiorna spesso, come pacchetti `.deb` firmati da un repository apt di progetto, sul modello MuonPi ([MuonPi releases](https://github.com/MuonPi/muondetector/releases)). Il rilascio è scaglionato: prima 2-3 scuole "canarino", poi il resto della flotta. Per l'A/B del sistema operativo ci sono tre candidati. Raspberry Pi Connect "Remote updates" usa il tryboot nativo, che torna indietro da solo se l'aggiornamento fallisce, ma è **ancora sperimentale** (annunciato a marzo 2026) e ha bug aperti ([Raspberry Pi news](https://www.raspberrypi.com/news/new-remote-updates-on-raspberry-pi-connect/); [rpi-image-gen issue #225](https://github.com/raspberrypi/rpi-image-gen/issues/225)). Mender costa 34 $ al mese ogni 50 dispositivi nel piano Basic, ma un post del blog dello stesso vendor riporta cifre diverse ([Mender plans](https://mender.io/pricing/plans); [Mender blog](https://mender.io/blog/the-simplicity-of-menders-pricing-approach)). balenaCloud è il più chiavi in mano ma anche il più caro: 329 $ al mese nel piano Pilot ([balena](https://www.balena.io/pricing)). Per 100 rivelatori si consiglia di valutare Connect nel pilota e di tenere Mender Basic (circa 820 $ l'anno, stima) come piano B.

Per l'SSH su un singolo rivelatore dietro il NAT della scuola servono soluzioni con fallback sulla porta 443. Tailscale inoltra il traffico WireGuard cifrato attraverso relay DERP su HTTPS quando l'UDP è bloccato ([Tailscale](https://tailscale.com/docs/reference/connection-types)). **Headscale**, il server di controllo open source, con DERP integrato su una VPS UE costa pochi euro al mese e tiene i dati in UE ([Headscale DERP](https://headscale.net/stable/ref/derp/)). Il piano gratuito di Tailscale è limitato a 50 risorse taggate e, secondo fonti terze, all'uso non commerciale ([Tailscale pricing](https://tailscale.com/pricing/)). WireGuard puro su UDP è sconsigliato nelle scuole. Come **secondo canale indipendente** si consiglia Raspberry Pi Connect per organizzazioni, a 0,50 $ per dispositivo al mese, con shell remota, tag, provisioning in massa e audit log ([Raspberry Pi](https://www.raspberrypi.com/news/raspberry-pi-connect-for-organisations-plus-full-screen-support/)). Così un errore di configurazione della VPN non rende irraggiungibile la flotta. Per il monitoraggio si usa il watchdog hardware tramite systemd, con `RuntimeWatchdogSec` non superiore a circa 15 s, che è il massimo del timer del SoC ([forum RPi](https://forums.raspberrypi.com/viewtopic.php?t=254539)). Il servizio di acquisizione usa `WatchdogSec` e `Restart=always`. Grafana Alloy invia le metriche in push verso VictoriaMetrics o Prometheus self-hosted, con una connessione solo in uscita che funziona dietro NAT ([Grafana Alloy](https://grafana.com/docs/alloy/latest/tutorials/send-metrics-to-prometheus/)). Il free tier di Grafana Cloud (10.000 serie) si esaurisce con circa 100 Pi se non si filtrano le metriche ([Grafana](https://x.com/grafana/status/1924516350409752631)). L'allarme più utile è il più semplice: "nessun upload da N ore", con e-mail al docente referente.

Per il provisioning si costruisce un'immagine unica con rpi-image-gen. Al primo avvio il dispositivo genera la propria chiave e si registra con un token monouso. L'etichetta riporta un QR code. Il docente configura il Wi-Fi dal telefono tramite l'hotspot di **comitup** ([comitup](https://github.com/davesteele/comitup/blob/main/README.md)). Per WPA2-Enterprise comitup non ha un modulo EAP, quindi serve un file `.nmconnection` preparato dal team. Il costo ricorrente stimato della gestione flotta per 100 unità va da circa **900 € l'anno** (apt + Headscale + Connect + monitoraggio self-hosted) a circa **1.700 € con Mender Basic (stime)**.

## Il GPS serve solo quando rivelatori di scuole diverse devono parlarsi

La precisione temporale necessaria dipende da cosa si vuole misurare. Ci sono quattro livelli.

**Dentro un rivelatore** la coincidenza triplice è già fatta in hardware dalla porta AND, quindi il Raspberry Pi deve solo contare e marcare gli eventi. Su un Pi 4 con Linux standard il timestamp di un interrupt GPIO ha un jitter dell'ordine dei **microsecondi**: le misure di un singolo autore danno 2-7 µs sul jitter grezzo del PPS. PREEMPT_RT usato senza accorgimenti peggiora la situazione, perché sposta il gestore dell'interrupt in un thread ([Cuckoo Escapement](https://git.supported.systems/warehack.ing/cuckoo-escapement/raw/branch/main/README.md)). pigpio campiona al massimo a 1 µs e può perdere per costruzione gli impulsi da 100-300 ns ([pigpio](https://www.neura.market/ai-tools-directory/all/joan2937-pigpio)). Per conteggi, rate, spettri angolari e studi di pressione e temperatura, l'**NTP** con un errore di millisecondi basta. Gli impulsi dei MAX961 verso il GPIO vanno però allungati a 2-10 µs con un monostabile, oppure catturati da un microcontrollore **(stima prudenziale, nessuna misura pubblicata sulla larghezza minima rilevabile)**.

**Tra rivelatori nella stessa scuola**, se si vuole correlare due unità senza un cavo di coincidenza, l'NTP su Wi-Fi non basta: su Wi-Fi l'errore è di millisecondi o decine di millisecondi ([time-nuts 2017](https://www.febo.com/pipermail/time-nuts/2017-January/103352.html)). Un gruppo che ha sincronizzato rivelatori derivati da CosmicWatch via Internet ha misurato 2,03 ms di differenza ed è passato al GPS ([Kearns](https://www.stvincent.edu/assets/docs/academic-conference/academic-conference-201/Phys_Kearns_Synchronization_of_Muon_Detectors.pdf)). La soluzione più semplice resta un **cavo che porta l'uscita AND da un'unità all'altra**, come nel "telescopio" a due unità di CosmicWatch v3X ([arXiv:2508.12111](https://arxiv.org/html/2508.12111v2)).

**Tra scuole diverse** il GPS con PPS è indispensabile. HiSPARC cerca coincidenze tra stazioni con una finestra di **2 µs** ([HiSPARC](https://www.hisparc.nl/oud/en/news/newsitem/article/translate-to-english-coincidenties-showers-gemeten-door-meerdere-stations/cache/925fcbc3137c1ee163a593068b48bfb6/)). Per scuole a 1-10 km di distanza la finestra fisica è di circa 3-33 µs (d/c, stima). Con un GPS e chrony l'orologio di sistema scende sotto il µs (offset RMS di 199-823 ns nelle misure citate), ma l'evento letto via GPIO resta affetto dal jitter di interrupt, quindi l'errore complessivo stimato è di circa 1-5 µs. Basta per finestre di 10-50 µs. Con rate di coincidenza di circa 1 Hz per stazione le coincidenze accidentali con una finestra di 50 µs sono circa 9 al giorno per coppia **(stima)**. Le coincidenze vere tra stazioni a chilometri di distanza, con aree di circa 0,1 m², sono eventi rarissimi (energie ≳10¹⁷ eV, stima da verificare con una simulazione). Questa è un'aspettativa da chiarire con le scuole prima di promettere "la rete che vede i grandi sciami". EEE, con telescopi molto più grandi, ha osservato coincidenze tra stazioni a circa 1,5 km e ha cercato correlazioni a lunga distanza con finestre fino al millisecondo ([Abbrescia, Centro Fermi](https://agenda.centrofermi.it/event/54/contributions/355/attachments/277/380/AbbresciaCFMar18.pdf)).

**Per ricostruire la direzione degli sciami** servono circa 10-30 ns. HiSPARC misura uno scarto tra stazioni con σ = 18,9 ns, usando un contatore a 200 MHz agganciato al PPS ([arXiv:1908.01622](https://arxiv.org/pdf/1908.01622); [firmware HiSPARC](https://docs.hisparc.nl/firmware/messages.html)). MuonPi usa il "timemark" hardware del ricevitore u-blox, con decine di ns e una σ di circa 50 ns tra due rivelatori sovrapposti ([MuonPi](https://muonpi.org/first_results.html)). A questo livello Linux non arriva da solo. Serve un **contatore hardware disciplinato dal PPS**, che oggi costa pochi euro: un Pico RP2040 con PIO conta i cicli tra i fronti con 16 ns di risoluzione a 125 MHz ([PicoPET](https://github.com/dorsic/PicoPET)). Il modulo GNSS deve essere di tipo timing: il NEO-M8T dà un PPS entro 20 ns a cielo aperto, ma solo entro 500 ns in interni ([Waveshare NEO-M8T HAT](https://www.waveshare.com/product/neo-m8t-gnss-timing-hat.htm)). L'antenna va quindi portata a una finestra o sul tetto, come raccomanda QuarkNet ([poster QuarkNet](https://new.quarknet.org/sites/default/files/BUITRAGO_D_poster.pdf)). Il tempo di volo tra le barre (circa 0,3 ns su 10 cm) richiederebbe TDC da decine di ps e discriminatori a frazione costante: è fuori scopo per un prodotto scolastico.

La decisione proposta è di **mettere un RP2350 o RP2040 sulla scheda di interfaccia fin dall'inizio**, collegato all'AND e alle tre uscite dei canali, con un connettore per un modulo GNSS timing opzionale. Il microcontrollore conta i singoli di ogni canale in hardware, cosa utile anche per il collaudo di tenuta alla luce e per il monitoraggio del dark rate. Misura la durata degli impulsi come time-over-threshold, il che ha valore didattico. Marca ogni evento con il secondo GPS e il contatore del PPS, con passi di circa 7-8 ns. Il costo marginale è di pochi euro, più il modulo GNSS e l'antenna da montare solo nelle scuole che partecipano alle coincidenze in rete (ordine di grandezza 30-100 €, stima, prezzi 2026 non recuperati). Senza GPS lo stesso firmware funziona con l'NTP. Sul server ogni evento si salva con il tempo in ns in un int64 e con i flag di qualità GPS. Il coincidence finder gira sulle finestre ormai chiuse (per esempio a T+24 h), come il riassunto notturno di HiSPARC, così da includere i dati arrivati in ritardo dagli spool locali.

## Architettura end-to-end e costi indicativi

Lungo la catena del segnale, ogni barra, già a tenuta di luce e visibile sul telaio, è collegata con il proprio cavo schermato, bloccato da fermacavi, al front-end INFN a meno di 30 cm. Se le barre devono stare più lontane, il segnale va amplificato vicino alla barra. Il front-end produce i tre impulsi dei comparatori e l'AND hardware, che escono sia sui LEMO del pannello sia verso la scheda di interfaccia. La scheda di interfaccia è la novità proposta. Riceve i 12 V e li protegge (TVS, eFuse/ideal diode, PTC). Alimenta il Pi 5 dal GPIO e il front-end con un ramo filtrato separato. Ospita il microcontrollore di timestamp e conteggio, il connettore GNSS, i sensori di temperatura (uno sul lato SiPM), i LED e il cicalino. Sul Pi 5 girano il daemon di acquisizione, che legge il microcontrollore via USB o UART e l'MCP3424 via I2C e valida il bias, lo spool locale, l'uploader HTTPS, il client MQTT su WSS, l'agente Alloy, Headscale e Connect, il tutto su un root in sola lettura. Il server centrale in UE comprende reverse proxy, broker MQTT con ACL, servizio di ingest, PostgreSQL/TimescaleDB con RLS, object storage per i grezzi, job di qualità dati e coincidenze, Keycloak, la web app delle scuole, Grafana interno e le pagine pubbliche.

| Voce | Ordine di grandezza | Stato del dato |
|---|---|---|
| Alimentatore 12 V Mean Well GST25E12 | ~12 € | Fonte ([Alimentatorishop](https://www.alimentatorishop.com/en/external-power-supplies/gst25e12-p1j-meanwell-power-supply-wallmount-25w-12v-input-100-240-vac)) |
| Protezioni, buck, filtri sulla scheda di interfaccia | ~5-15 € | Stima |
| Microcontrollore di timestamp (RP2040/RP2350) e componenti | ~5-15 € | Stima |
| Modulo GNSS timing e antenna (solo dove serve) | ~30-100 € | Stima |
| Raspberry Pi 5 2 GB | da verificare | Prezzo 2026 non recuperato |
| SD industriale pSLC | ~15-30 € | Stima |
| Meccanica (telaio/teca PMMA + vani in alluminio + stampa FR) | ~80-150 € | Stima; estruso Hammond ~44 $ da fonte ([Newark](https://www.newark.com/hammond/1455t2201rd/pcb-box-enclosure-aluminum-red/dp/30Y9630)) |
| Cavi schermati, connettori con blocco, 4 LEMO 00, fermacavi, schiume, maniglia | ~60-150 € | Stima |
| Pre-compliance EMC (una tantum) | ~500-1.500 € | Stima |
| CE completa RED + EN 18031 + EN 61326-1 (una tantum) | ~5.000-15.000 € | Stima; base EMC 3.000-8.000 $ da fonte ([electronics-lab](https://www.electronics-lab.com/forums/threads/emc-compliance-testing.27689/latest)) |
| Hosting piattaforma, 100 rivelatori | ~50-130 €/mese | Stima |
| Raspberry Pi Connect, 100 dispositivi | ~50 $/mese | Fonte ([Raspberry Pi](https://www.raspberrypi.com/news/raspberry-pi-connect-for-organisations-plus-full-screen-support/)) |
| Mender Basic (opzionale), 100 dispositivi | ~68 $/mese | Fonte con conflitto di listino |

SiPM, scintillatori, front-end INFN e manodopera di assemblaggio e collaudo non sono coperti dalle note e vanno aggiunti. Escluse queste voci, la parte di "prodotto" (alimentazione, interfaccia, meccanica, cablaggio, storage, senza GNSS) vale circa **200-370 € per unità più il Pi (stima)**.

## Roadmap in tre fasi con criteri di passaggio misurabili

| Fase | Durata indicativa | Contenuto | Criterio per passare alla fase successiva |
|---|---|---|---|
| 1. Prototipo (3-5 unità) | 3-4 mesi (stima) | Scheda di interfaccia v1, telaio a vista con vani per elettronica e Pi, misura del segnale in funzione della lunghezza del cavo barra-scheda, firmware del microcontrollore, daemon su libgpiod, piattaforma minima (ingest, TimescaleDB, una dashboard), un'unità con GNSS. Prova termica 15-30 °C, misura del ripple sul catodo, pre-compliance EMC di una giornata | Singoli di ogni barra invariati con luce accesa e spenta e con il test della torcia; deriva di guadagno compensata misurata; nessun falso trigger dal boost; 30 giorni senza intervento umano; nessun flag di sottotensione |
| 2. Pilota (2-3 scuole, 6-10 unità) | un semestre scolastico (stima) | Indagine sulla rete di ogni scuola (porte, proxy, captive portal, `tailscale netcheck`); accordi art. 28 GDPR; Keycloak e dashboard per scuola; rilascio canarino via apt e prova di Connect Remote Update; un paio di unità con GNSS in scuole vicine; raccolta dei feedback dei docenti | Uptime e tasso di upload misurati; nessun rivestimento o cavo di barra danneggiato, oppure danni rilevati dall'allarme sul rate dei singoli; zero perdite di dati dopo blackout; tempo di riparazione di una SD; docenti autonomi nella configurazione Wi-Fi |
| 3. Produzione (lotti da 20-100) | 4-6 mesi per CE e industrializzazione (stima) | Revisione hardware, fascicolo tecnico, test RED + EN 18031 + EN 61326-1, iscrizione al Registro AEE, banco di collaudo di fine linea (tenuta alla luce di ogni barra, rate per canale, bias), manuali in italiano, supporto | DoC firmata; marcatura CE e RAEE; collaudo automatizzato ripetibile |

Il pilota è la fase che fa risparmiare di più. Quasi tutte le incognite che possono costringere a ridisegnare il prodotto, come la reale apertura delle reti scolastiche, la temperatura nelle aule o l'uso effettivo da parte dei docenti, emergono solo lì. Conviene quindi spendere per la CE completa dopo il pilota, non prima.

## Punti aperti da verificare

| Punto | Perché conta | Come chiuderlo |
|---|---|---|
| Vbd, pendenza guadagno/OV e capacità dell'AFBR-S4N22P014M | Definiscono overvoltage, sensibilità termica ed effetto dei cavi | Leggere il datasheet DS103 e misurare il lotto |
| Dove sta l'elemento di compensazione termica rispetto ai SiPM | Se è sul PCB compensa la temperatura sbagliata | Verificare lo schema INFN; prova in camera climatica |
| Larghezza degli impulsi dei MAX961 verso il GPIO | Impulsi da 100-300 ns rischiano di andare persi | Oscilloscopio; aggiungere un monostabile o il microcontrollore |
| Spike del boost sugli ingressi dei comparatori | Falsi trigger e immunità EMC | Misura con sonda a molla; filtri e layout |
| Applicabilità della EN 18031 e copertura delle DoC Raspberry Pi | Determina Modulo A o Organismo Notificato | Laboratorio o consulente CE; documentazione RPi |
| Limite SELV/ES1 (60 V DC) e possibile classificazione come "giocattolo" | Analisi dei rischi e direttive applicabili | Testo della EN 62368-1; parere del consulente |
| Porte aperte, proxy con ispezione TLS e captive portal nelle scuole italiane | Scelta tra MQTT/WSS e HTTPS; VPN | Indagine tecnica nelle scuole pilota |
| Maturità di Raspberry Pi Connect Remote Update | OTA del sistema operativo | Prova nel pilota; piano B Mender |
| Prezzi 2026 di Pi 5, GNSS timing, LEMO, hosting, Mender | Budget | Preventivi da distributori e fornitori |
| Qualificazione ACN del cloud per un servizio erogato da UniTo/INFN | Hosting conforme per la PA | DPO e ufficio ICT di ateneo; GARR/INFN Cloud |
| Rate di coincidenze vere tra scuole | Promessa didattica della rete | Simulazione degli sciami con area e distanze reali |
| Dimensioni delle barre e lunghezza/tipo del cavo che esce da ciascuna | Telaio, posizione del front-end, necessità di amplificare vicino alla barra | Disegno meccanico; misura di ampiezza e tempo di salita in funzione della lunghezza |
| Robustezza del rivestimento delle barre all'uso in classe | Con le barre a vista è l'unica barriera alla luce | Test di trasporto e manipolazione nel pilota; controllo periodico con lampada e torcia |

## Conclusione

La lezione dei progetti reali è che, in un rivelatore didattico, le fragilità stanno quasi sempre attorno ai SiPM e non nei SiPM: un'alimentazione rumorosa (Cosmic Pi), un connettore che si stacca (QuarkNet), un upload manuale (e-Lab), una fessura nel nastro (HiSPARC). Con le barre lasciate a vista, la scelta giusta per un oggetto didattico, rivestimento e cavo di ogni barra diventano i componenti da proteggere e da monitorare. Per questo l'investimento con il rendimento più alto non è un front-end migliore, che il progetto INFN già offre, ma una **scheda di interfaccia** che risolve insieme quattro problemi: alimentazione protetta, isolamento del rumore, timestamp in hardware e conteggio dei singoli per il collaudo. Insieme al root in sola lettura, trasforma un buon strumento da laboratorio in un oggetto che sopravvive a un weekend senza corrente e a un docente che non conosce Linux.

La seconda indicazione riguarda i requisiti normativi. Dal 2025 le norme EN 18031 rendono obbligatorio quello che una buona gestione di flotta farebbe comunque: identità per dispositivo, nessuna password di default e aggiornamenti firmati. Progettare la piattaforma con questi vincoli fin dal prototipo costa poco e trasforma la certificazione da ostacolo finale a verifica di cose già fatte. Infine, il valore scientifico della rete tra scuole va presentato con onestà: con rivelatori piccoli a chilometri di distanza la rete misurerà soprattutto rate, correlazioni con pressione e temperatura e qualche rara coincidenza. Predisporre il GPS in hardware senza montarlo ovunque mantiene aperta la possibilità di misure più ambiziose senza farla pagare a ogni scuola.

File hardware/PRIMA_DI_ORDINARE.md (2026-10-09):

# Prima di ordinare i PCB — stato della revisione A2

Questa revisione (A2) è la scheda INFN "Riv. Cosmici 2024 — Amplif, alim, soglie"
(S. Gallian, rev. A) ricostruita in KiCad, **verificata collegamento per collegamento
contro lo schema originale** e simulata per intero. In più c'è uno stadio d'uscita a
3,3 V per la lettura con un Raspberry Pi.

## Cosa è stato verificato

| Verifica | Come | Esito |
|---|---|---|
| Schema KiCad = schema INFN | confronto pin per pin con `docs/schema_originale_INFN.pdf` | OK, dopo la correzione di V2 (sotto) |
| Netlist del file `.kicad_sch` = modello dati | `simulation/netlist_from_kicad.py` (estrae le reti per geometria) | OK: 0 reti diverse; gli unici pin liberi sono i NC voluti (U5.4, U7.4, U8.1/5/8, U9.1) |
| Piedinature degli integrati | datasheet MAX961, MCP1402, LT3461, LP2985, MCP1825, LT1636, TLC555, 74LVC1G17 | OK |
| Footprint | SOT-23 (1 = B, 2 = E, 3 = C), SOT-23-5/6, SO-8, SOT-223 (tab = GND), 3296W (cursore al centro), LED (pin 1 = catodo) | OK |
| PCB | autorouter del generatore + DRC geometrico + verifica di connettività | 0 errori DRC, 0 reti aperte |
| Funzionamento della scheda intera | `simulation/ltspice/verifica_ltspice.py` (ngspice), 21 controlli | tutti superati (vedi sotto) |

## Cosa è cambiato rispetto alla ricostruzione precedente

1. **V2 (soglia): errore di ricostruzione corretto.** Nell'originale V2 è un
   *potenziometro*: l'estremo alto va a R19 (+3,6 V), il cursore a R17 → TH e l'estremo
   basso a R18. In KiCad il cursore era cortocircuitato all'estremo alto (V2 usato come
   reostato). Ora è come nell'originale. Il campo della soglia resta da ~1 mV a ~1,29 V.
2. **Uscita per il Raspberry Pi (J4).** I GPIO del Pi lavorano a 3,3 V e **non
   tollerano 5 V**. Il vecchio buffer a 2 transistor era alimentato a 5 V e, simulandolo,
   ritardava gli impulsi (~440 ns), li accorciava di ~100 ns e spingeva l'uscita a
   −0,7 V. È stato sostituito da **U9 = 74LVC1G17** (buffer CMOS con trigger di Schmitt,
   alimentato a +3V3) + **R23 = 33 Ω** in serie, adattata al cavo coassiale. Il risultato
   è una copia esatta di CMP_Q a 0–3,3 V, con 8 ns di ritardo.
3. **Libreria `riv.kicad_sym`** rigenerata (contiene il simbolo del 74LVC1G17).
4. **PCB e Gerber** rigenerati, con il buffer finalmente sulla scheda.
5. **BOM** generata dallo stesso modello dati (`hardware/generator/gen_bom.py`).

Nessun valore del circuito originale INFN è stato cambiato.

## Punti da decidere prima del montaggio (non richiedono modifiche al PCB)

1. **LT3461 (U1): uscita del boost oltre il limite assoluto.** Con R3 = 270k e
   R1‖R2‖R22 = 8,39k, VOUT40 = 1,255 V × (1 + 270/8,39) = **41,7 V nominali**.
   Il datasheet LT3461 dà **40 V come massimo assoluto** su VOUT e SW (38 V è l'uscita
   massima dichiarata). La nota INFN indica 40,2 V misurati: la scheda originale
   funziona, ma è al limite. *Consiglio:* **R3 = 255k (1%)** porta VOUT40 a
   **39,4 V**. In simulazione il bias si regola ancora fino a 39 V (38,4 V con
   V1_POS = 0,76). Stesso footprint 0805, cambia solo il valore in BOM.
2. **Condensatori d'uscita dei regolatori.** Il datasheet LP2985 chiede **≥ 2,2 µF**
   in uscita (X7R) e l'MCP1825 **≥ 1 µF**. Nell'originale CF4 e CF7 (uscite LP2985)
   e CF9 (uscita MCP1825) sono da 100 nF. *Consiglio:* montare **2,2 µF X7R 0805
   (≥ 10 V)** su CF4, CF7 e CF9. Stesso footprint, nessuna modifica al PCB.
3. **L1 (47 µH, RS 693-4344)**: il footprint è un 5×5/6×6 mm generico. Controllare le
   dimensioni dei pad sul datasheet della parte che si ordina.
4. **J4**: il footprint è un header 2,54 mm; il LEMO va a pannello e si collega con un
   cavetto. **J2 (TTL_OUT) esce a 5 V: non collegarlo al Raspberry Pi.**
5. **Soglia (V2) con il SiPM AFBR-S4N22P014M.** Simulando il sensore vero
   (Broadcom, Farnell 4351470: VBD 32,5 V, 160 pF, recharge 55 ns, guadagno
   7,3·10⁶ a 12 V di sovratensione) si ha, al bias di 38,4 V (sovratensione ~5,9 V,
   guadagno ~3,6·10⁶):

   | fotoelettroni | picco al comparatore |
   |---|---|
   | 1 | ~10 mV |
   | 3 | ~40 mV |
   | 5 | ~71 mV |
   | 10 | ~156 mV |
   | muone (≥ 80 p.e.) | ~1,0–1,2 V (saturato) |

   Con V2 a metà corsa bassa (TH ≈ 104 mV) la soglia è a **~7 p.e.**: i dark count
   (1–2 p.e., anche con un po' di crosstalk) sono scartati e i muoni sono tutti
   contati con ampio margine. Per scendere a ~3 p.e. bastano ~40–50 mV su TH. La
   taratura finale va fatta sulla scheda vera, guardando CMP_IN all'oscilloscopio.
6. **Temperatura: il bias si compensa da solo.** La caduta di D1 (−2 mV/°C),
   moltiplicata dall'LT1636, alza BIAS di **+28 mV/°C**, quasi uguale al coefficiente
   di VBD del SiPM (~30 mV/°C). Simulando da −10 a +50 °C la sovratensione resta tra
   5,85 e 5,94 V. Con R3 = 255k (punto 1) a 50 °C il boost ha ancora 0,3 V di margine
   sopra il bias (39,4 V contro 39,1 V); a temperatura ambiente il margine è ~1 V.

## Ultimi passi in KiCad (consigliati)

Aprire `hardware/riv_cosmici.kicad_pro` con KiCad ≥ 6, lanciare **ERC** sullo schema,
**riempire le zone** (tasto B) e lanciare il **DRC** sul PCB. Il generatore ha già fatto
un DRC geometrico e la verifica di connettività, ma il DRC ufficiale di KiCad è il
controllo finale. I Gerber pronti sono in `hardware/gerber/` (anche come
`riv_cosmici_gerber.zip`): 2 strati, 80 × 55 mm, foratura PTH in Excellon.

## Collegamento al Raspberry Pi

| Scheda | Raspberry Pi |
|---|---|
| J4 pin 1 (segnale 0–3,3 V) | un GPIO, es. GPIO17 (pin 11), meglio con 330 Ω in serie |
| J4 pin 2 (GND) | GND (es. pin 9) |

Ogni muone produce un impulso positivo di **≥ 84 ns** (minimo garantito dal latch
C9/R16 del MAX961), ~150–270 ns per un muone tipico. Va contato **sul fronte di
salita, a interrupt** (rilevamento dei fronti in hardware del GPIO, es. `libgpiod` con
eventi `RISING_EDGE`): leggere il pin in polling perderebbe impulsi così brevi.
Il rate atteso su una paletta 10×10 cm è ~1,7 eventi/s.

## Ordine su JLCPCB e prima accensione

I file per JLCPCB (Gerber, BOM, CPL) e le opzioni del modulo d'ordine sono in
[`hardware/jlcpcb/`](jlcpcb/LEGGIMI.md). U1 (LT3461), U3 (MAX961) e U8 (LT1636) sono
esclusi dal montaggio e si saldano a mano, uno alla volta. Anche U5, U7 (LP2985-3.6),
D1 e gli header J1–J4 si saldano a mano (esauriti o non riconosciuti a JLCPCB): vanno
montati **per primi**, prima del passo 1.

1. **Senza i tre chip**, 5 V su J3: +3V3 ≈ 3,30 V, +3V6 ≈ 3,60 V, VREF_B ≈ 3,6 V,
   assorbimento di pochi mA.
2. **Salda U1**: VOUT40 ≈ 41,7 V (≈ 39,4 V con R3 = 255k).
3. **Salda U8, senza SiPM**: regola V1 fino a BIAS = 38,4 V (campo ~28,6–41,5 V).
4. **Salda U3**: regola TH con V2 (es. ~100 mV); CMP_Q deve restare a 0 V, LED spento.
5. **Collega il SiPM**: impulsi su CMP_IN, LED che lampeggia al passaggio dei muoni.

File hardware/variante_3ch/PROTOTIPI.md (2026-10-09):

# Due prototipi da laboratorio (scheda a 3 canali)

Obiettivo: costruire **2 rivelatori** da usare come prototipi nei laboratori, con le
scuole coinvolte tramite accordi. **Niente marcatura CE, niente piattaforma, niente
GPS**: si spende il minimo e si misura se il circuito funziona davvero. Le scelte "da
prodotto" del rapporto `reports/Architettura rivelatori per le scuole.md` restano per
dopo, se e quando servirà.

## Cosa ordinare

| Voce | Dove | Quantità | Costo (IVA incl.) |
|---|---|---|---|
| PCB 103 × 215 mm + montaggio SMD | JLCPCB (`jlcpcb/`) | **5 PCB, montaggio su 2** | ~110–140 € (stima: rifare il preventivo) |
| Chip da saldare a mano, strip, ponticelli, connettori KK | Mouser (`BOM_mouser_2prototipi.csv`) | per 2 schede + 1 chip di scorta | ~127 € |
| SiPM AFBR-S4N22P014M | Mouser (stesso file) | 6 | 125 € (togliere se già disponibili) |
| Raspberry Pi Zero 2 W + scheda SD 16–32 GB | qualsiasi rivenditore | 2 | ~50 € (o Pi già in laboratorio) |
| Alimentatori 5 V | qualsiasi rivenditore | 4 (2 per la scheda, 2 per il Pi) | ~30 € |
| Base in plexiglass, distanziali M3, staffe stampate per le barre | laboratorio | 2 | ~20–40 € |
| LEMO | — | — | già disponibili |
| **Totale** | | | **~460–510 €** (≈ 335–385 € senza SiPM) |

Note sui prezzi:
- **JLCPCB:** il minimo è 5 PCB, ma il montaggio si può chiedere solo su 2 (campo
  "PCBA Qty"). Le 3 schede nude restano come ricambio. Spedizione: scegliere la più
  economica (Global Standard Direct). Il numero va confermato col preventivo reale.
- **Mouser:** sopra 75 € la spedizione è gratuita, con dazi inclusi. MAX961, LT1636 e
  LT3461A sono fine vita e non restituibili: la scorta di un pezzo per tipo serve anche
  a riparare un prototipo.
- **Pi Zero 2 W** al posto del Pi 5: costa circa un quarto, consuma poco e per contare
  impulsi e leggere l'ADC basta. Va benissimo anche un Pi 3/4 già presente in laboratorio.

## Come montarlo (senza scatola)

- **Una base in plexiglass** (taglio laser) con la scheda e il Pi sopra, su distanziali
  M3 da 10 mm negli 8 fori di fissaggio. Niente involucro chiuso: per un prototipo da
  laboratorio è più comodo per misurare con l'oscilloscopio.
- **Le barre** (già a tenuta di luce) impilate su due staffe stampate in 3D. Cavo dalla
  barra alla scheda: **coassiale RG174 o RG316, fino a 50 cm** (simulato: il segnale cala
  del 10 % e resta 7 volte sopra la soglia), fermato con una fascetta a ogni estremo.
- **Connettore barra → scheda: Molex KK 254 a 2 poli, NON LEMO.** Nel cavo la calza
  porta i +38 V del bias, mentre i LEMO della scheda hanno la carcassa a massa: un
  connettore diverso rende impossibile lo scambio. Sulla scheda, al posto della strip,
  l'header 22-27-2021 (con rampa di aggancio, entra negli stessi fori di J101/J201/J301);
  sul cavo il connettore 22-01-3027 con due contatti 08-50-0114:
  **pin 1 = conduttore centrale (segnale), pin 2 = calza (bias)**, guaina
  termorestringente sulla calza.
- **Il Pi lontano dai SiPM** (dall'altro lato della base), perché scalda.
- **Alimentazione:** due alimentatori separati, uno per la scheda (5 V su J3) e uno per il
  Pi. Costa pochi euro in più e toglie un dubbio: se poi le misure sono pulite, si
  prova con un alimentatore unico.
- **Collegamenti al Pi:** uscite dei canali e AND verso 4 GPIO con cavetti Dupont, J6 (I²C)
  ai pin 3/5/6 per il monitor delle tensioni.

## Software

- Conteggio e tempi degli impulsi con libgpiod (timestamp del kernel), salvataggio in CSV
  sulla SD.
- `software/monitor_tensioni.py` per i bias e l'alta tensione.
- Ora di rete (NTP): basta per i conteggi.
- Accesso remoto, se serve: Raspberry Pi Connect (gratuito per uso individuale).
- Nessuna piattaforma centrale per ora: i dati si copiano dalla SD o via rete.

## Prime prove (in quest'ordine)

1. Alimentazioni e alta tensione **senza SiPM** (`../PRIMA_DI_ORDINARE.md`); regolare il
   bias con V1 e verificarlo con il monitor delle tensioni.
2. **Larghezza degli impulsi al GPIO:** in simulazione sono circa 0,3 µs. Verificare che
   il Pi li conti tutti confrontando il suo conteggio con quello di un oscilloscopio o di
   un contatore. Se ne perde, la correzione è allungare l'impulso (un condensatore).
3. **Tenuta alla luce di ogni barra:** conteggio di un singolo canale a luce accesa e
   spenta, torcia lungo il rivestimento.
4. **Disturbi:** con l'oscilloscopio sull'ingresso del comparatore, cercare i picchi del
   survoltore; poi provare il Pi alimentato dalla stessa sorgente della scheda.
5. **Temperatura:** registrare per qualche giorno conteggi, bias e temperatura della
   stanza, per vedere quanto deriva il guadagno.

Quello che si impara da queste prove decide la versione successiva.

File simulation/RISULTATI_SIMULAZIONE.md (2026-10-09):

# Simulazione della catena di segnale

> **Novità: simulazione della scheda COMPLETA** — alimentazioni, boost, bias,
> front-end, comparatore, uscite, 555 — in `ltspice/` (schema LTspice + netlist,
> verificata con ngspice). Vedi la sezione in fondo e `ltspice/LEGGIMI.md`.
> Le sezioni "Buffer d'uscita" e "Treno completo fino ad Arduino" descrivono la
> variante precedente (buffer a 2 transistor a 5 V), sostituita dal 74LVC1G17 a 3,3 V
> per la lettura con Raspberry Pi.

Transitorio non lineare (MNA + backward Euler, BJT Ebers-Moll) dell'intera catena:
impulso SiPM → C7 → Q1 BFR93A → Q2 MMBTH81 → C11 → MAX961 (comportamentale con
isteresi ±2 mV e latch via C9/R16). Impulso SiPM modellato come corrente
esponenziale, τ = 45 ns, 0,5 pC per fotoelettrone (guadagno ~3·10⁶).

## Punto di lavoro DC (Vcc = 3,3 V)

| Nodo | V |
|---|---|
| Base Q1 | 0,60 V |
| Collettore Q1 / base Q2 | 2,48 V |
| Emettitore Q2 | 3,07 V |
| Collettore Q2 (nodo D) | 0,41 V |
| Ic(Q1) / Ic(Q2) | 0,82 mA / 0,41 mA |

Coerente con la topologia: Q1 polarizzato dalla retroazione R11/R9, Q2 in
conduzione debole con degenerazione R13.

## Risposta all'impulso (grafici: `sim_catena.png`, `sim_ampiezze.png`)

- Guadagno di carica: **~35 mV per fotoelettrone** al comparatore (regione lineare).
- Ampiezze al nodo del comparatore: 2 p.e. → 71 mV, 10 p.e. → 386 mV,
  20 p.e. → 811 mV; **clipping a ~1,19 V** oltre ~40 p.e. (saturazione di Q1/Q2).
- Uscita del comparatore: impulsi puliti, larghezza 90–220 ns (cresce con
  l'ampiezza, time-over-threshold), compatibili con il driver MCP1402.
- La rete C9/R16 (100 pF/1 kΩ) produce sul latch-enable un impulso di ~3,3 V con
  τ = 100 ns sul fronte di salita di Q: blocca ri-trigger sul ringing per ~70 ns.
- Range soglia (V2): ~2 mV … 1,29 V ⇒ discriminazione regolabile da **<1 p.e. fino
  a ~40 p.e.**; un muone in scintillatore (centinaia di p.e.) è sempre sopra soglia.
- Monostabile 555: T = 1,1·R20·C21 = 1,1·100k·100n = **11 ms** di lampeggio LED
  per evento (calcolo analitico, non simulato nel transitorio veloce).

## Limiti del modello

- Parametri BJT tipici (IS=50 fA, βF=90/70): il guadagno reale può variare ±30%.
- MAX961 ideale (4,5 ns di ritardo e limiti di slew non modellati).
- Cavo Fileca non modellato (aggiunge ~100 pF/m sul nodo di ingresso: riduce
  leggermente ampiezza e velocità del fronte).
- Per una verifica più accurata: `riv_cosmici_frontend.cir` con ngspice/LTspice,
  sostituendo i modelli BJT con quelli ufficiali NXP/onsemi.

## Come rilanciarla

- Qui: `python3 sim_catena.py` (richiede numpy/matplotlib).
- ngspice: `ngspice riv_cosmici_frontend.cir`
- LTspice: apri il .cir come netlist e premi Run. Parametri in testa al file
  (NPE = fotoelettroni, VTH = soglia).

## Sequenza di muoni (`sim_muoni.py`)

Treno di eventi sul solver circuitale (finestra 200 µs, rate muoni accelerato a
60 kHz per visualizzazione; rate reale ~1,7 Hz su paletta 10×10 cm):

- **Muoni**: arrivi poissoniani, carica ~Landau (Moyal, mediana ~250 p.e., min 80).
- **Dark count SiPM**: 200 kHz a 1–2 p.e.
- **Soglia 100 mV (~3 p.e.)**: tutti i 7 muoni della finestra hanno generato un
  trigger TTL (larghezza 160–224 ns), tutti i ~55 dark count sono stati rigettati.
  Anche due muoni distanti ~1,5 µs sono risolti separatamente.
- Scala reale (`sim_muoni_reale.png`): a 1,7 Hz il LED (11 ms/evento) ha un
  duty di ~2%; probabilità che un secondo muone cada nel tempo morto del
  monostabile: ~1,9% (il trigger TTL su J2 non ne è influenzato: il tempo morto
  della catena veloce è solo ~0,5 µs, dominato dal ritorno sotto soglia).

Grafici: `sim_muoni_treno.png`, `sim_muoni_reale.png`.

## Buffer d'uscita: CMP_Q vs TTL come ingresso (`sim_buffer.py`)

Modello transitorio del buffer a 2 transistor (2N2222) con **carica immagazzinata**
(transit time TF/TR + Cje/Cjc): è quella carica a produrre lo *storage time* che
allunga l'impulso.

**Com'è fatto CMP_Q**: è un'onda quadra 0→3,3 V la cui **larghezza = time-over-threshold**,
cioè quanto il segnale amplificato resta sopra soglia. Non è fissa: muone tipico
(180 p.e.) → **188 ns**, muone grande (500 p.e.) → 231 ns. Il TTL (dopo MCP1402) è
la stessa onda scalata a 0→5 V con ~25 ns di ritardo di propagazione; la **larghezza
si conserva** (il MCP1402 non allunga l'impulso).

**Cosa cambia mettendo il buffer dopo il TTL:**
- Ingresso identico in larghezza (188 ns), ma **5 V invece di 3,3 V** → Q3 riceve più
  corrente di base (4,3 mA vs 2,6 mA) → **satura più a fondo** → immagazzina più carica
  → **storage time maggiore in spegnimento**.
- Uscita da CMP_Q: **174 ns**. Uscita da TTL: **192 ns** → **+18 ns più larga**.
- Il fronte di discesa dell'uscita arriva **+37 ns più tardi** con il TTL (~25 ns di
  ritardo del MCP1402 + ~12 ns di storage time in più).
- In più restano le ragioni già dette: dopo il TTL il buffer è ridondante (il MCP1402
  è già un driver migliore) e le due uscite non sono più indipendenti.

Conclusione: da CMP_Q l'impulso è **più stretto e più fedele** all'originale; dopo il
TTL è **leggermente più largo e più ritardato**. Per contare muoni su Arduino la
differenza (±20 ns) è irrilevante; conta di più l'indipendenza dei rami → **CMP_Q**.

Grafico: `sim_buffer.png`.

## Treno completo end-to-end fino ad Arduino (`sim_treno_completo.py`)

Catena intera muone → SiPM → ampli → comparatore → CMP_Q → **buffer 5 V** → pin
Arduino, con il buffer preso da **CMP_Q** (uscita comparatore) e alimentato a **5 V**
(Arduino Uno/Nano). Il front-end è il solver circuitale non lineare; il buffer è
comportamentale ma calibrato sul modello dettagliato (`sim_buffer.py`): uscita 0→5 V,
salita ~storage-limited (τ≈26 ns), discesa netta (τ≈8 ns).

Finestra 200 µs, rate muoni accelerato a 60 kHz (reale ~1,7 Hz), dark count 200 kHz:

- **7 muoni → 7 impulsi CMP_Q → 7 conteggi Arduino.** I 46 dark count (1–2 p.e.)
  restano tutti sotto soglia: **0 falsi conteggi.**
- Ogni evento: la corrente del SiPM diventa un picco di ~1,2 V al comparatore (i muoni
  grossi saturano), CMP_Q è un'onda quadra 3,3 V larga il time-over-threshold, e il
  buffer la rigenera in un impulso **0→5 V** che l'Arduino conta sul fronte di salita
  (`attachInterrupt(RISING)`, ▼ nel grafico).
- Scala reale (`sim_treno_reale.png`): 60 s a 1,7 Hz → **media 1,68 conteggi/s**,
  fluttuazione poissoniana visibile bar-per-bar.

Grafici: `sim_treno_completo.png` (4 corsie), `sim_treno_zoom.png` (un muone in
dettaglio), `sim_treno_reale.png` (conteggi/s a scala reale).

## Verifica dallo schema: netlist estratta dal .kicad_sch (`verify_from_schematic.py`)

Fino a qui le simulazioni usavano una netlist trascritta a mano (indipendente dal
file KiCad). Questi due script chiudono il buco:

- **`netlist_from_kicad.py`**: legge `riv_cosmici.kicad_sch` ed estrae la netlist
  vera *per geometria* — valori dei componenti, posizione/rotazione/mirror dei
  simboli, fili, giunzioni, etichette e simboli di alimentazione uniti in nodi
  elettrici. La geometria dei pin viene dai `lib_symbols` del file stesso.
- **`verify_from_schematic.py`**: costruisce un solver MNA **generico** dalla
  netlist estratta (R, C, BJT, rail fissi) e simula il front-end partendo da lì.

Risultato: il front-end estratto dallo schema riproduce il simulatore di
riferimento **al millivolt** (punto di lavoro DC di B/C(Q1), E/C(Q2) identico;
picco al comparatore 1188 mV in entrambi).

**Prova che gli errori ora si vedono**: iniettando un errore in una copia dello
schema (R12: 1k → 4k7), il solver legge il nuovo valore e il punto di lavoro del
collettore di Q1 si sposta di **441 mV** → l'errore è rilevato. Lo stesso vale per
un errore di cablaggio: cambierebbe i nodi estratti e quindi il risultato.

Limite residuo: la geometria dei *pin* usa la trasformazione lib→foglio (verificata:
tutti i pin agganciano i fili); gli unici pin "flottanti" segnalati sono i NC
intenzionali (BYP dell'LP2985, ingressi inusati dell'LT1636). Il buffer aggiunto
(Q3/Q4) è nella netlist estratta ma non nel solver del front-end (che si ferma al
comparatore); per simularlo end-to-end si usa `sim_treno_completo.py`.

## Scheda completa: LTspice / ngspice (`ltspice/`)

Netlist e schema LTspice generati da `hardware/generator/netdata.py` (stesso modello
dati del KiCad); integrati con macromodelli dai datasheet, transistor e diodi con
modelli SPICE. Transitorio di 30 ms con accensione e 4 eventi a t = 10 ms
(`python ltspice/verifica_ltspice.py`, 21 controlli tutti superati):

| Grandezza | Simulato |
|---|---|
| +3V3 / +3V6 / riferimento 3,6 V | 3,30 / 3,60 / 3,60 V |
| VOUT40 (boost LT3461) | 41,65 V (calcolo: 1,255 V × 33,2) |
| BIAS SiPM (V1_POS = 0,76) | 38,44 V, raggiunto dopo 2,4 ms |
| Punto di lavoro Q1 B / C, Q2 C | 0,59 / 2,47 / 0,42 V (come `sim_catena.py`) |
| Corrente dai 5 V | 38 mA |
| Muone 250 p.e. al comparatore | 1,14 V (saturato) |
| CMP_Q / TTL J2 / GPIO Pi | 3,28 / 4,99 / 3,27 V |
| Larghezza impulso al GPIO, ritardo | 300 ns, 8 ns |
| Dark count 1 p.e. | ~10 mV → nessun impulso |
| Muoni a 1,5 µs | risolti separatamente |
| LED (555) | 10,9 ms |

SiPM simulato: **Broadcom AFBR-S4N22P014M** (VBD 32,5 V, 160 pF, recharge 55 ns,
guadagno 7,3·10⁶ a 12 V OV → ~3,6·10⁶ e ~0,58 pC/p.e. a 5,9 V OV). Ampiezza al
comparatore: 1 p.e. ≈ 10 mV, 3 p.e. ≈ 40 mV, 5 p.e. ≈ 71 mV, 10 p.e. ≈ 156 mV
(l'amplificatore è leggermente espansivo), muoni saturati a ~1,0–1,2 V. Soglia di
default 104 mV ≈ 7 p.e. Impulso minimo in uscita **~84 ns** (latch C9/R16).

Temperatura (−10…+50 °C): BIAS sale di +28 mV/°C grazie a D1, contro ~30 mV/°C di
VBD → sovratensione costante entro 0,1 V (5,85–5,94 V).

Correzione di ricostruzione emersa dal confronto con l'originale: **V2 è un
potenziometro** (cursore → R17), non un reostato. Il campo della soglia non cambia.

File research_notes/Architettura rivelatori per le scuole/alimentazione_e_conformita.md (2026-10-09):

# Alimentazione, rumore e conformità CE: rivelatore di muoni a SiPM per le scuole (scheda 3 canali + Raspberry Pi)

> Nota metodologica: in questa sessione il fetch diretto delle pagine era bloccato dal proxy (raspberrypi.com, docs.broadcom.com, arxiv.org, farnell.com non raggiungibili). Tutti i fatti sotto vengono da risultati di ricerca web (estratti e sintesi dei motori di ricerca). Le URL sono quelle delle fonti primarie restituite, ma i valori numerici vanno ricontrollati sui PDF originali prima di finire in una specifica di progetto. Ho segnato come "Inferenza" i calcoli fatti da me.

## 1. Opzioni per alimentare insieme scheda rivelatore e Raspberry Pi; requisiti ufficiali Pi

### Takeaway
Per Pi 5 la soluzione più semplice e robusta è l'alimentatore ufficiale USB-C PD 27 W (5.1 V / 5 A), da cui si deriva il 5 V per la scheda SiPM con filtro e protezioni. In alternativa, un ingresso unico a 12 V (alimentatore da muro CE, circa 12 €) con buck a bordo, che genera un 5 V/5 A per il Pi e un 5 V "pulito" separato per l'analogico, dà più margine sulla caduta nei cavi, più controllo sul rumore e connettori meno fragili. PoE+ conviene solo se la scuola ha switch PoE; per Pi 4 bastano 5.1 V / 3 A.

### Cited Findings
- **Pi 5 e alimentatori non da 5 A.** Se il Pi 5 non rileva un alimentatore da 5 V / 5 A, il firmware limita le porte USB a 600 mA (invece di 1.6 A), disattiva il boot da USB se non si preme il tasto di accensione e mostra un avviso di alimentazione limitata. Raspberry Pi ammette che con periferiche a basso consumo un alimentatore da 3 A può bastare. — [Raspberry Pi whitepaper "USB Power Delivery on Raspberry Pi 5" (RP-009856-WP)](https://pip-assets.raspberrypi.com/categories/685-app-notes-guides-whitepapers/documents/RP-009856-WP-1-USB%20Power%20delivery%20on%20Raspberry%20Pi%205.pdf)
- **Override del limite USB.** Il flag `usb_max_current_enable=1` in config.txt porta il limite USB a 1.6 A. Il firmware lo imposta da solo quando negozia 5 V / 5 A via PD o quando nella EEPROM è impostato `PSU_MAX_CURRENT=5000`, e questo riabilita anche il boot da USB. È utile se il Pi 5 viene alimentato da un buck a bordo, che non fa negoziazione PD. — [stesso whitepaper](https://pip-assets.raspberrypi.com/categories/685-app-notes-guides-whitepapers/documents/RP-009856-WP-1-USB%20Power%20delivery%20on%20Raspberry%20Pi%205.pdf)
- **Alimentatore ufficiale 27 W.** Fornisce fino a 5.1 V / 5 A; gli altri profili PD sono 9 V / 3 A, 12 V / 2.25 A e 15 V / 1.8 A. — [CanaKit, scheda prodotto](https://canakit.com/official-raspberry-pi-5-power-supply-27w-usb-c.html)
- **Pi 4.** L'alimentatore consigliato è 5.1 V / 3 A USB-C; i 5.1 V servono a compensare la caduta su cavo e connettore. — [raspberry.tips](https://raspberry.tips/en/raspberrypi-einsteiger/best-raspberry-pi-power-supply); [techsparx](https://techsparx.com/linux-sbc/raspberry-pi/pi4-usb-power-limit.html)
- **Soglia di sottotensione.** È circa 4.63 V. Sul Pi 4 il PMIC MxL7704 imposta un flag "sticky" quando l'ingresso scende sotto 4.63 V e il firmware mostra l'icona del fulmine; anche le schede più vecchie usavano la stessa soglia. La fonte è un forum ufficiale ma non la documentazione: da verificare. — [Raspberry Pi Forums](https://forums.raspberrypi.com/viewtopic.php?p=1724251)
- Il codice di throttling nel log per la sottotensione è 0x50005. — [Raspberry Pi Forums](https://forums.raspberrypi.com/viewtopic.php?t=270660)
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

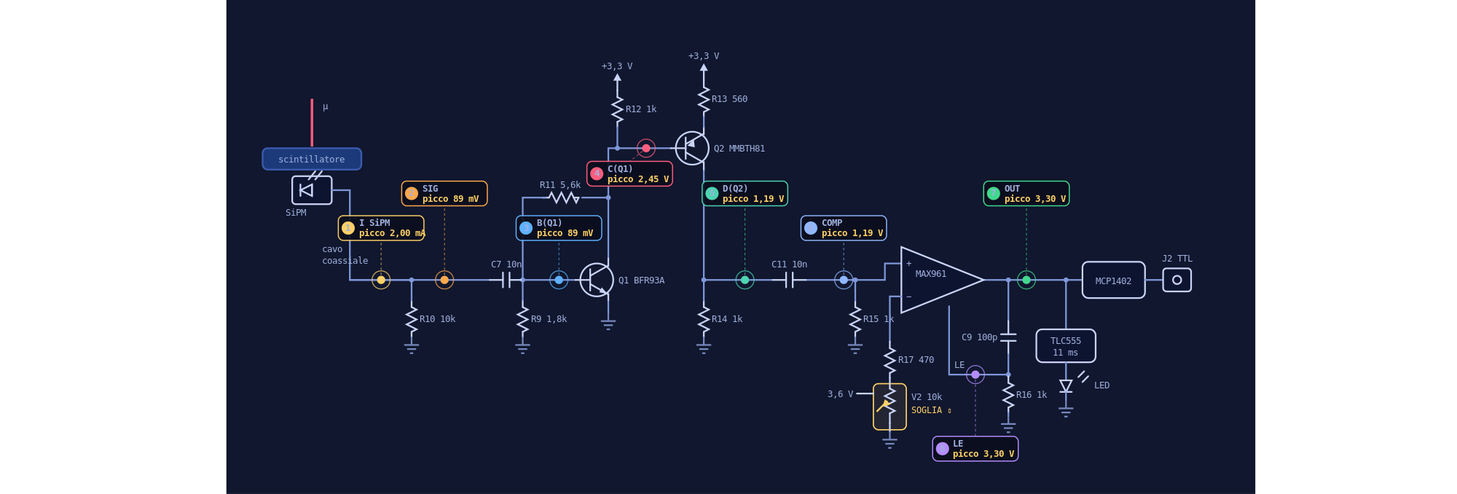
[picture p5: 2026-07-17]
hardware/previews/anteprima_schematico.png

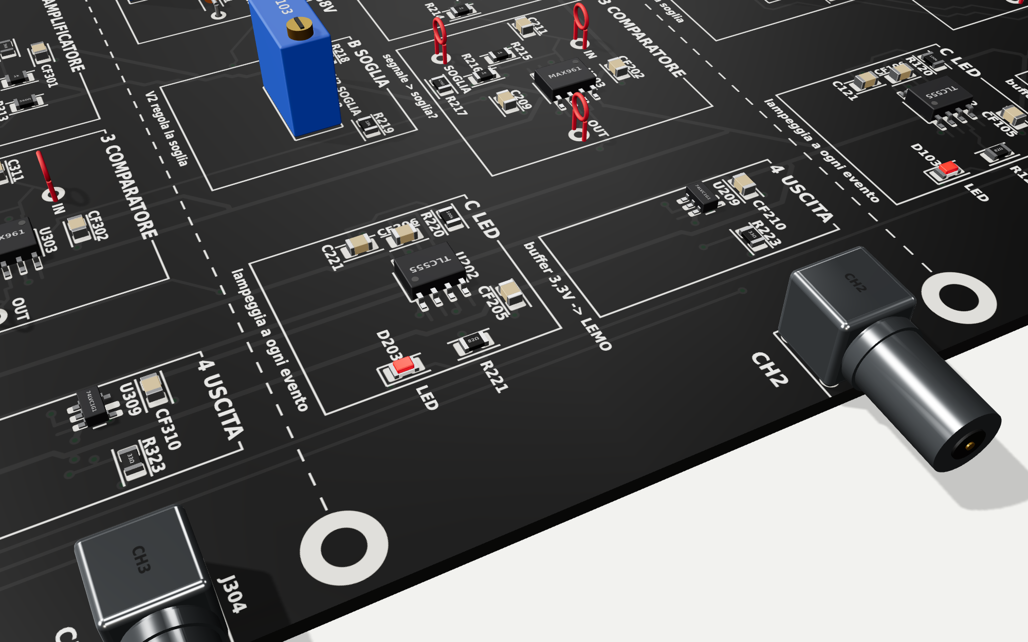
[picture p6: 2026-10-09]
hardware/render3d/out/3ch/render_lemo_nero.png

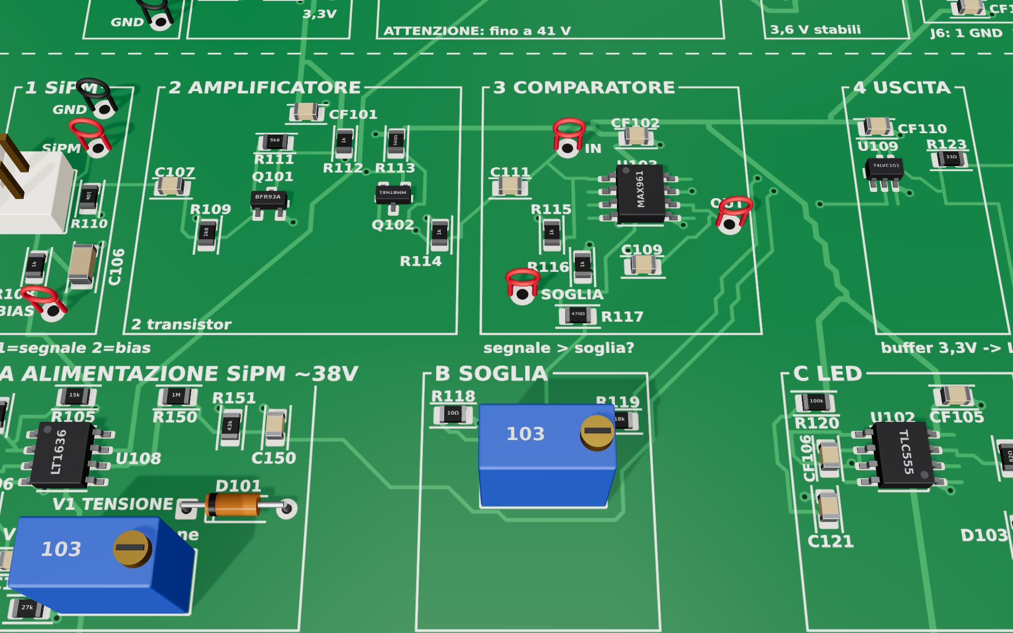
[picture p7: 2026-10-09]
hardware/render3d/out/3ch/render_ch1.png

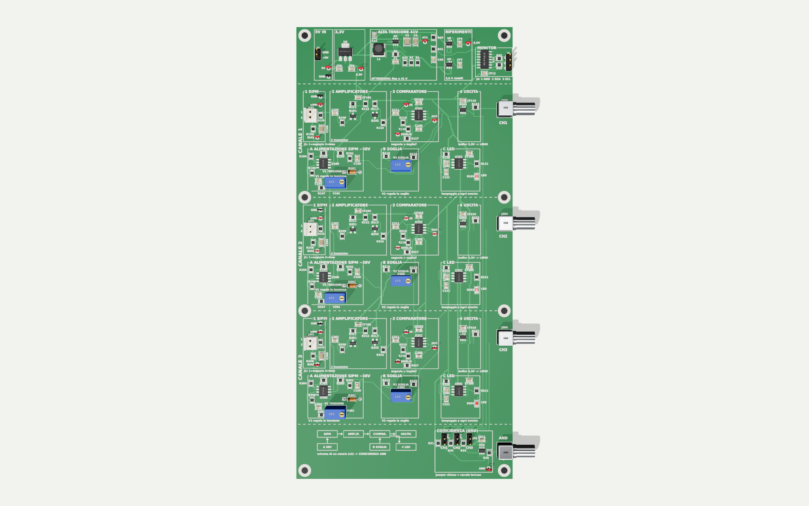
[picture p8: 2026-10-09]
hardware/render3d/out/3ch/render_top.png

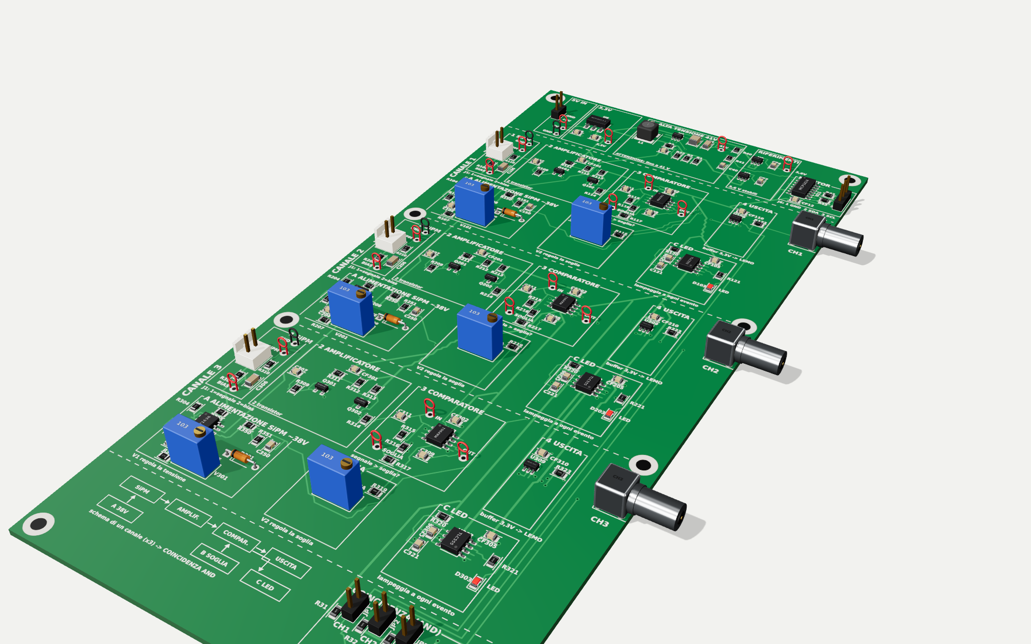
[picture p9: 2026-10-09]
hardware/render3d/out/3ch/render_iso.png

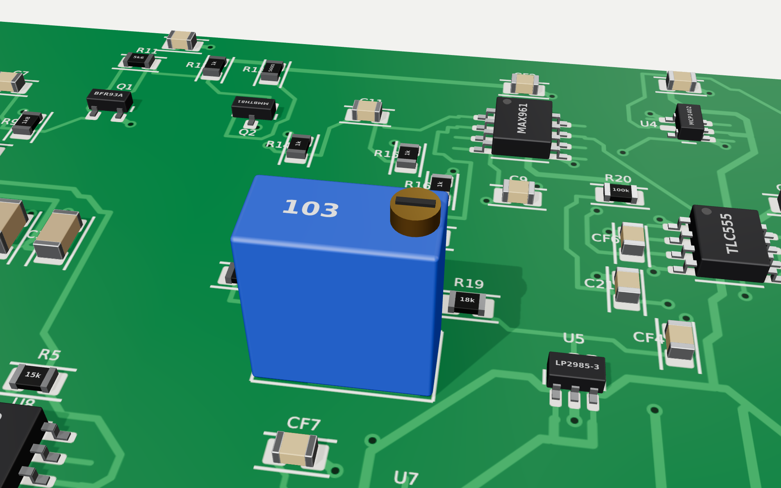
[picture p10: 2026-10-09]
hardware/render3d/out/1ch/render_detail.png

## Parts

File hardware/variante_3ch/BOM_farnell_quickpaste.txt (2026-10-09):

4024725, 6, U1 alta tensione (versione A, come INFN)
2519484, 16, U?03 comparatore
2889103, 20, D?01 (a pezzi, non bobina da 5000)
2834673, 20, jumper JP1-3
4351470, 15, SiPM

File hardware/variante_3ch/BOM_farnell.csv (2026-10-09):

Farnell Part Number | Manufacturer Part Number | Manufacturer | Quantity | Line Note
4024725 | LT3461AES6#TRMPBF | Analog Devices | 6 | U1 alta tensione SOT-23-6
2519484 | MAX961ESA+ | Analog Devices | 16 | U103 U203 U303 comparatore SO-8
 | LT1636CS8#PBF | Analog Devices | 16 | U108 U208 U308 op-amp SO-8 (NON la versione MSOP CMS8)
 | LP2985AIM5-3.6/NOPB | Texas Instruments | 12 | U5 U7 LDO 3.6V SOT-23-5
2889103 | 1N4148-TAP | Vishay | 20 | D101 D201 D301 diodo DO-35
 | 61304011121 | Wurth Elektronik | 6 | strip maschio 1x40 passo 2.54: header (anche J6) e test point
 | M7566-05 | Harwin | 20 | ponticello 2.54 per JP1-JP3
4351470 | AFBR-S4N22P014M | Broadcom | 15 | SiPM

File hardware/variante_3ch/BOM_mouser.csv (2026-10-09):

Manufacturer Part Number | Manufacturer | Quantity | Description
LT3461AES6#TRMPBF | Analog Devices | 6 | U1 alta tensione SOT-23-6
MAX961ESA+ | Analog Devices | 16 | U103 U203 U303 comparatore SO-8
LT1636CS8#PBF | Analog Devices | 16 | U108 U208 U308 op-amp SO-8 (NON la versione MSOP CMS8)
LP2985AIM5-3.6/NOPB | Texas Instruments | 12 | U5 U7 LDO 3.6V SOT-23-5
1N4148-TAP | Vishay | 20 | D101 D201 D301 diodo DO-35
61304011121 | Wurth Elektronik | 6 | strip maschio 1x40 passo 2.54: header (anche J6) e test point
M7566-05 | Harwin | 20 | ponticello 2.54 per JP1-JP3
AFBR-S4N22P014M | Broadcom | 15 | SiPM
22-27-2021 | Molex | 17 | header KK 254 2 poli per J101 J201 J301 (15 + 2)
22-01-3027 | Molex | 18 | connettore KK 254 2 poli lato cavo barra (15 + 3)
08-50-0114 | Molex | 40 | contatti a crimpare KK 254 (30 + scorta)

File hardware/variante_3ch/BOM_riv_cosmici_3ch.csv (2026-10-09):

Rif. | Qta | Valore/Parte | Package | Codice ordine | Note
C1 | 1 | 22pF | 0805
C2 | 1 | 1uF 100V | 1210 |  | dielettrico X7R, 100V (nodo VOUT40 ~41 V)
C3 C106 C206 C306 | 4 | 100n 100V | 1206 |  | X7R 100V (nodi 40V/38,4V)
C22 | 1 | 1uF | 0805
C40 C104 C150 C204 C250 C304 C350 CF4 CF7 CF8 CF9 CF11 CF12 CF101 CF102 CF105 CF106 CF110 CF201 CF202 CF205 CF206 CF210 CF301 CF302 CF305 CF306 CF310 | 28 | 100n | 0805 |  | X7R 50V (CF = disaccoppiamento)
C107 C207 C307 | 3 | 10nF | 0805
C109 C209 C309 | 3 | 100pF | 0805
C111 C211 C311 | 3 | 10n | 0805
C121 C221 C321 | 3 | 100nF | 0805
D101 D201 D301 | 3 | 1N4148 | DO-35 |  | assiale DO-35 (o 1N4148W SOD-123 adattando il footprint)
D103 D203 D303 | 3 | LED rosso | 0805 |  | LED rosso 0805 (pin 1 = catodo)
J3 | 1 | PWR_5V | Header 2.54 1x2 |  | pin 1 = GND, pin 2 = +5V
J5 J104 J204 J304 | 4 | LEMO EPL.00.250.NTN | LEMO 00 (EPL.00.250.NTN) |  | presa a gomito da circuito stampato (gia' disponibili)
J6 | 1 | I2C_RPI | header 1x3 2,54
J101 | 1 | SiPM_CH1 | Molex KK 254 2 poli (22-27-2021)
J201 | 1 | SiPM_CH2 | Molex KK 254 2 poli (22-27-2021)
J301 | 1 | SiPM_CH3 | Molex KK 254 2 poli (22-27-2021)
JP1 | 1 | INCL_CH1 | Header 2.54 1x2
JP2 | 1 | INCL_CH2 | Header 2.54 1x2
JP3 | 1 | INCL_CH3 | Header 2.54 1x2
L1 | 1 | 47uH | SMD 5x5/6x6 | RS 693-4344 | verificare l'ingombro della parte RS effettiva contro il footprint 5x5
Q101 Q201 Q301 | 3 | BFR93A | SOT-23 | RS 892-2365
Q102 Q202 Q302 | 3 | MMBTH81 | SOT-23 | RS 104-1196
R1 R31 R32 R33 R110 R210 R310 | 7 | 10k | 0805
R2 | 1 | 68k | 0805
R3 | 1 | 270k | 0805
R22 | 1 | 220k | 0805
R30 R123 R223 R323 | 4 | 33R | 0805 |  | terminazione serie del cavo verso Raspberry Pi
R40 R150 R250 R350 | 4 | 1M | 0805 |  | partitore monitor (alto)
R41 R151 R251 R351 | 4 | 43k | 0805 |  | partitore monitor (basso)
R42 R43 | 2 | 100R | 0805
R104 R204 R304 | 3 | 1k2 | 0805
R105 R205 R305 | 3 | 15k | 0805
R106 R120 R206 R220 R306 R320 | 6 | 100k | 0805
R107 R207 R307 | 3 | 27k | 0805
R108 R112 R114 R115 R116 R208 R212 R214 R215 R216 R308 R312 R314 R315 R316 | 15 | 1k | 0805
R109 R209 R309 | 3 | 1k8 | 0805
R111 R211 R311 | 3 | 5k6 | 0805
R113 R213 R313 | 3 | 560R | 0805
R117 R217 R317 | 3 | 470R | 0805
R118 R218 R318 | 3 | 10R | 0805
R119 R219 R319 | 3 | 18k | 0805
R121 R221 R321 | 3 | 82R | 0805
TP1 TP2 TP3 TP4 TP5 TP6 TP101 TP102 TP103 TP104 TP105 TP106 TP201 TP202 TP203 TP204 TP205 TP206 TP301 TP302 TP303 TP304 TP305 TP306 | 24 | test point | test point THT |  | pin di strip header 2,54 (o anello Keystone 5000 rosso / 5001 nero)
U1 | 1 | LT3461 | SOT-23-6 (ThinSOT) | Farnell 4024725
U5 U7 | 2 | LP2985AIM5-3.6 | SOT-23-5 | RS 812-2417
U6 | 1 | MCP1825S-3302 | SOT-223 | RS 669-5092
U10 | 1 | 74LVC1G11 | SOT-23-6 (ThinSOT) |  | SN74LVC1G11DBVR, AND a 3 ingressi (coincidenza)
U11 | 1 | MCP3424 | SOIC-14 |  | MCP3424-E/SL, ADC I2C del monitor tensioni (LCSC C640884)
U102 U202 U302 | 3 | TLC555/LMC555 | SO-8 | RS 196-2112 (LMC555CM)
U103 U203 U303 | 3 | MAX961 | SO-8 | RS 189-9176
U108 U208 U308 | 3 | LT1636 | SO-8 | Farnell 4020771
U109 U209 U309 | 3 | 74LVC1G17 | SOT-23-5 |  | SN74LVC1G17DBVR (TI) o equivalente; buffer 3,3 V verso Raspberry Pi
V101 V102 V201 V202 V301 V302 | 6 | 10k | Trimmer 3296W |  | Bourns 3296W-1-103LF o equivalente
(fuori scheda) | 3 | SiPM AFBR-S4N22P014M | - | Farnell 4351470 | uno per canale, su PCB separato incollato allo scintillatore

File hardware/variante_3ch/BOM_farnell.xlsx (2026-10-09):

Farnell Part Number | Quantity | Manufacturer Part Number | Manufacturer | Line Note
4024725 | 6 | LT3461AES6#TRMPBF | Analog Devices | U1 alta tensione (versione A, come INFN)
2519484 | 16 | MAX961ESA+ | Analog Devices | U?03 comparatore
 | 16 | LT1636CS8#PBF | Analog Devices | U?08 op-amp - SOLO SO-8 (CS8), non MSOP (CMS8)
 | 12 | LP2985AIM5-3.6/NOPB | Texas Instruments | U5 U7 LDO 3.6V SOT-23-5
2889103 | 20 | 1N4148-TAP | Vishay | D?01 (a pezzi, non bobina da 5000)
 | 5 | 61304011121 | Wurth Elektronik | strip 1x40 2.54 mm: header + test point
2834673 | 20 | MC-2228CG | Multicomp | jumper JP1-3
4351470 | 15 | AFBR-S4N22P014M | Broadcom | SiPM

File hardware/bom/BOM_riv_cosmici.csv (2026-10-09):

Rif. | Qta | Valore/Parte | Package | Codice ordine | Note
C1 | 1 | 22pF | 0805
C2 | 1 | 1uF 100V | 1210 |  | dielettrico X7R, 100V (nodo VOUT40 ~41 V)
C3 C6 | 2 | 100n 100V | 1206 |  | X7R 100V (nodi 40V/38,4V)
C4 CF1 CF2 CF3 CF4 CF5 CF6 CF7 CF8 CF9 CF10 | 11 | 100n | 0805 |  | X7R 50V (CF = disaccoppiamento)
C7 | 1 | 10nF | 0805
C9 | 1 | 100pF | 0805
C11 | 1 | 10n | 0805
C21 | 1 | 100nF | 0805
C22 | 1 | 1uF | 0805
D1 | 1 | 1N4148 | DO-35 |  | assiale DO-35 (o 1N4148W SOD-123 adattando il footprint)
D3 | 1 | LED rosso | 0805 |  | LED rosso 0805 (pin 1 = catodo)
J1 | 1 | SiPM | Header 2.54 1x2 |  | verso scintillatore, cavo Fileca schermato; calza = bias 38,4V
J2 | 1 | TTL_OUT | Header 2.54 1x2 |  | uscita 0-5 V (MCP1402): NON collegare ai GPIO del Raspberry Pi
J3 | 1 | PWR_5V | Header 2.54 1x2 |  | pin 1 = GND, pin 2 = +5V
J4 | 1 | LEMO_OUT | Header 2.54 1x2 |  | uscita 0-3,3 V per GPIO Raspberry Pi; footprint header 2.54 -> LEMO a pannello via cavo
L1 | 1 | 47uH | SMD 5x5/6x6 | RS 693-4344 | verificare l'ingombro della parte RS effettiva contro il footprint 5x5
Q1 | 1 | BFR93A | SOT-23 | RS 892-2365
Q2 | 1 | MMBTH81 | SOT-23 | RS 104-1196
R1 R10 | 2 | 10k | 0805
R2 | 1 | 68k | 0805
R3 | 1 | 270k | 0805
R4 | 1 | 1k2 | 0805
R5 | 1 | 15k | 0805
R6 R20 | 2 | 100k | 0805
R7 | 1 | 27k | 0805
R8 R12 R14 R15 R16 | 5 | 1k | 0805
R9 | 1 | 1k8 | 0805
R11 | 1 | 5k6 | 0805
R13 | 1 | 560R | 0805
R17 | 1 | 470R | 0805
R18 | 1 | 10R | 0805
R19 | 1 | 18k | 0805
R21 | 1 | 82R | 0805
R22 | 1 | 220k | 0805
R23 | 1 | 33R | 0805 |  | terminazione serie del cavo verso Raspberry Pi
U1 | 1 | LT3461 | SOT-23-6 (ThinSOT) | Farnell 4024725
U2 | 1 | TLC555/LMC555 | SO-8 | RS 196-2112 (LMC555CM)
U3 | 1 | MAX961 | SO-8 | RS 189-9176
U4 | 1 | MCP1402 | SOT-23-5 | RS 668-4203
U5 U7 | 2 | LP2985AIM5-3.6 | SOT-23-5 | RS 812-2417
U6 | 1 | MCP1825S-3302 | SOT-223 | RS 669-5092
U8 | 1 | LT1636 | SO-8 | Farnell 4020771
U9 | 1 | 74LVC1G17 | SOT-23-5 |  | SN74LVC1G17DBVR (TI) o equivalente; buffer 3,3 V verso Raspberry Pi
V1 V2 | 2 | 10k | Trimmer 3296W |  | Bourns 3296W-1-103LF o equivalente
(fuori scheda) | 1 | SiPM AFBR-S4N22P014M | - | Farnell 4351470 | montato su PCB separato incollato allo scintillatore

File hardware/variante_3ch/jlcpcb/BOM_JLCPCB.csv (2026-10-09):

Comment | Designator | Footprint | JLCPCB Part #
CL21C220JBANNNC | C1 | 0805 | C1804
1210B105K101NT | C2 | 1210 | C24365
CC1206KKX7R0BB104 | C3,C106,C206,C306 | 1206 | C107181
CL21B105KBFNNNE | C22 | 0805 | C28323
CC0805KRX7R9BB104 | C40,C104,C121,C150,C204,C221,C250,C304,C321,C350,CF4,CF7,CF8,CF9,CF11,CF12,CF101,CF102,CF105,CF106,CF110,CF201,CF202,CF205,CF206,CF210,CF301,CF302,CF305,CF306,CF310 | 0805 | C49678
CL21B103KBANNNC | C107,C111,C207,C211,C307,C311 | 0805 | C1710
CL21C101JBANNNC | C109,C209,C309 | 0805 | C1790
NCD0805R1 | D103,D203,D303 | 0805 | C84256
SRN5040-470M | L1 | SMD 5x5mm | C1330294
BFR93AE6327HTSA1 | Q101,Q201,Q301 | SOT-23 | C513260
MMBTH81 | Q102,Q202,Q302 | SOT-23 | C190349
0805W8F1002T5E | R1,R31,R32,R33,R110,R210,R310 | 0805 | C17414
0805W8F6802T5E | R2 | 0805
0805W8F2703T5E | R3 | 0805
0805W8F2203T5E | R22 | 0805
0805W8F330JT5E | R30,R123,R223,R323 | 0805
0805W8F1004T5E | R40,R150,R250,R350 | 0805
0805W8F4302T5E | R41,R151,R251,R351 | 0805
0805W8F1000T5E | R42,R43 | 0805
0805W8F1201T5E | R104,R204,R304 | 0805
0805W8F1502T5E | R105,R205,R305 | 0805
0805W8F1003T5E | R106,R120,R206,R220,R306,R320 | 0805
0805W8F2702T5E | R107,R207,R307 | 0805
0805W8F1001T5E | R108,R112,R114,R115,R116,R208,R212,R214,R215,R216,R308,R312,R314,R315,R316 | 0805
0805W8F1801T5E | R109,R209,R309 | 0805
0805W8F5601T5E | R111,R211,R311 | 0805
0805W8F5600T5E | R113,R213,R313 | 0805
0805W8F4700T5E | R117,R217,R317 | 0805
0805W8F100JT5E | R118,R218,R318 | 0805
0805W8F1802T5E | R119,R219,R319 | 0805
0805W8F820JT5E | R121,R221,R321 | 0805
MCP1825S-3302E/DB | U6 | SOT-223 | C148031
SN74LVC1G11DBVR | U10 | SOT-23-6 | C22046
MCP3424-E/SL | U11 | SOIC-14 | C640884
TLC555CDR | U102,U202,U302 | SOIC-8 | C6986
SN74LVC1G17DBVR | U109,U209,U309 | SOT-23-5 | C7836
3296W-1-103LF | V101,V102,V201,V202,V301,V302 | 3296W | C34846

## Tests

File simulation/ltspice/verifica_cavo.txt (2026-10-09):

misura                                                   0 m     0.5 m     1.0 m     2.0 m
muone 250 p.e.: picco ingresso comparatore (V)         1.134     1.164     1.174     1.176
muone 250 p.e.: uscita al Raspberry (V)                3.275     3.275     3.275     3.275
muone 40 p.e.: picco (V)                              0.8414    0.7538    0.6834    0.5996
muone 40 p.e.: uscita al Raspberry (V)                 3.275     3.275     3.275     3.275
rumore 1 p.e.: picco (V)                             0.00695  0.005245  0.004124  0.002283
rumore 1 p.e.: uscita comparatore (V), deve restare ~0 4.517e-08 7.175e-09 7.135e-09 7.116e-09
soglia (V)                                            0.1041    0.1041    0.1041    0.1041

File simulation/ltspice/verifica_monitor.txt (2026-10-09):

misura                                                          RIF       REALE      STRESS
bias SiPM a riposo (V)                                       38.441      38.441      38.441
ondulazione bias durante gli eventi (V)                   0.0023061   0.0023061    0.002306
muone 250 p.e.: picco all'ingresso del comparatore (V)       1.1281      1.1281      1.1281
muone 250 p.e.: durata impulso al Raspberry (s)          2.9004e-07  2.9004e-07  2.9003e-07
rumore 1 p.e.: picco (V), deve restare sotto soglia       0.0069475   0.0069475   0.0069454
rumore 1 p.e.: uscita comparatore (V), deve restare 0    2.7534e-07  2.7536e-07  7.2439e-09
muone 40 p.e.: picco (V)                                    0.84141     0.84141      0.8414
muone 40 p.e.: uscita al Raspberry (V)                       3.2746      3.2746      3.2746
muone ravvicinato: uscita al Raspberry (V)                   3.2746      3.2746      3.2746
punto di misura a t = 9,9 ms: 1.3970 V; a regime sara' 1.5848 V (VREG38 38.441 V x 43/1043). Il filtro 41 kohm x 100 nF ha tau = 4,1 ms: dopo l'accensione la lettura e' stabile in ~20 ms (qui la simulazione e' ancora nel transitorio).

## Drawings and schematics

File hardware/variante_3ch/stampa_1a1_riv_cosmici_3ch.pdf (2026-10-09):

## Riv. cosmici 3 canali - scala 1:1 - lato componenti

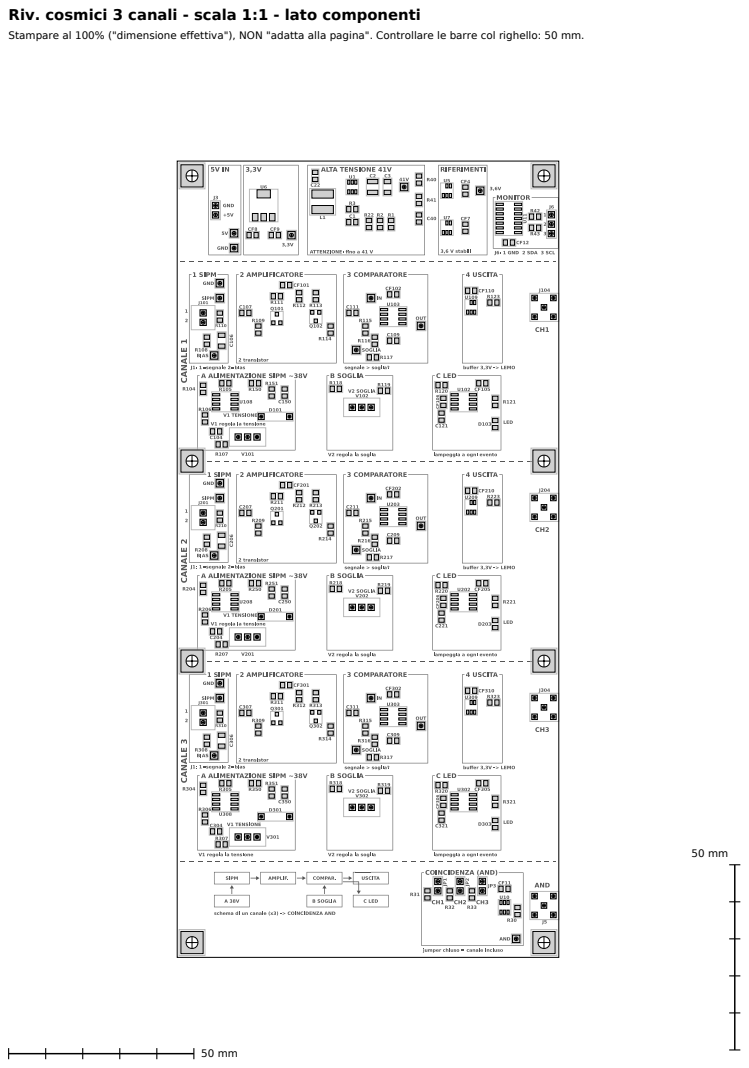
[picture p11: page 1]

Stampare al 100% ("dimensione effettiva"), NON "adatta alla pagina". Controllare le barre col righello: 50 mm.

## Riv. cosmici 3 canali - scala 1:1 - piste (nero sopra, grigio sotto)

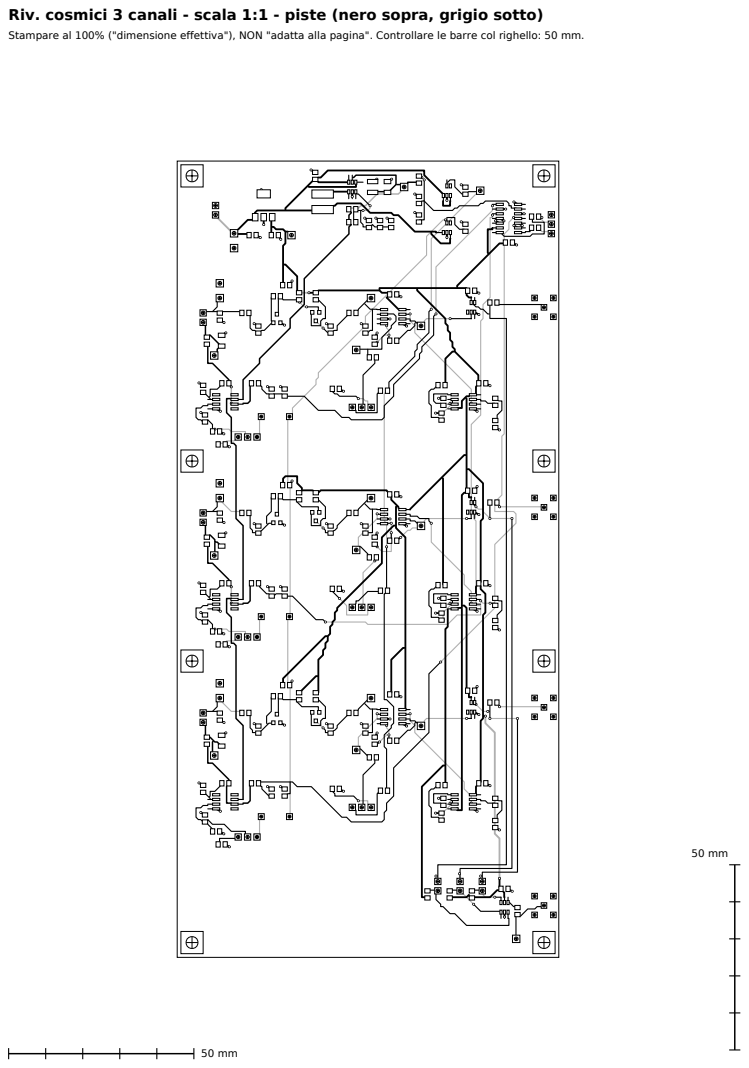
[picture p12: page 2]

Stampare al 100% ("dimensione effettiva"), NON "adatta alla pagina". Controllare le barre col righello: 50 mm.

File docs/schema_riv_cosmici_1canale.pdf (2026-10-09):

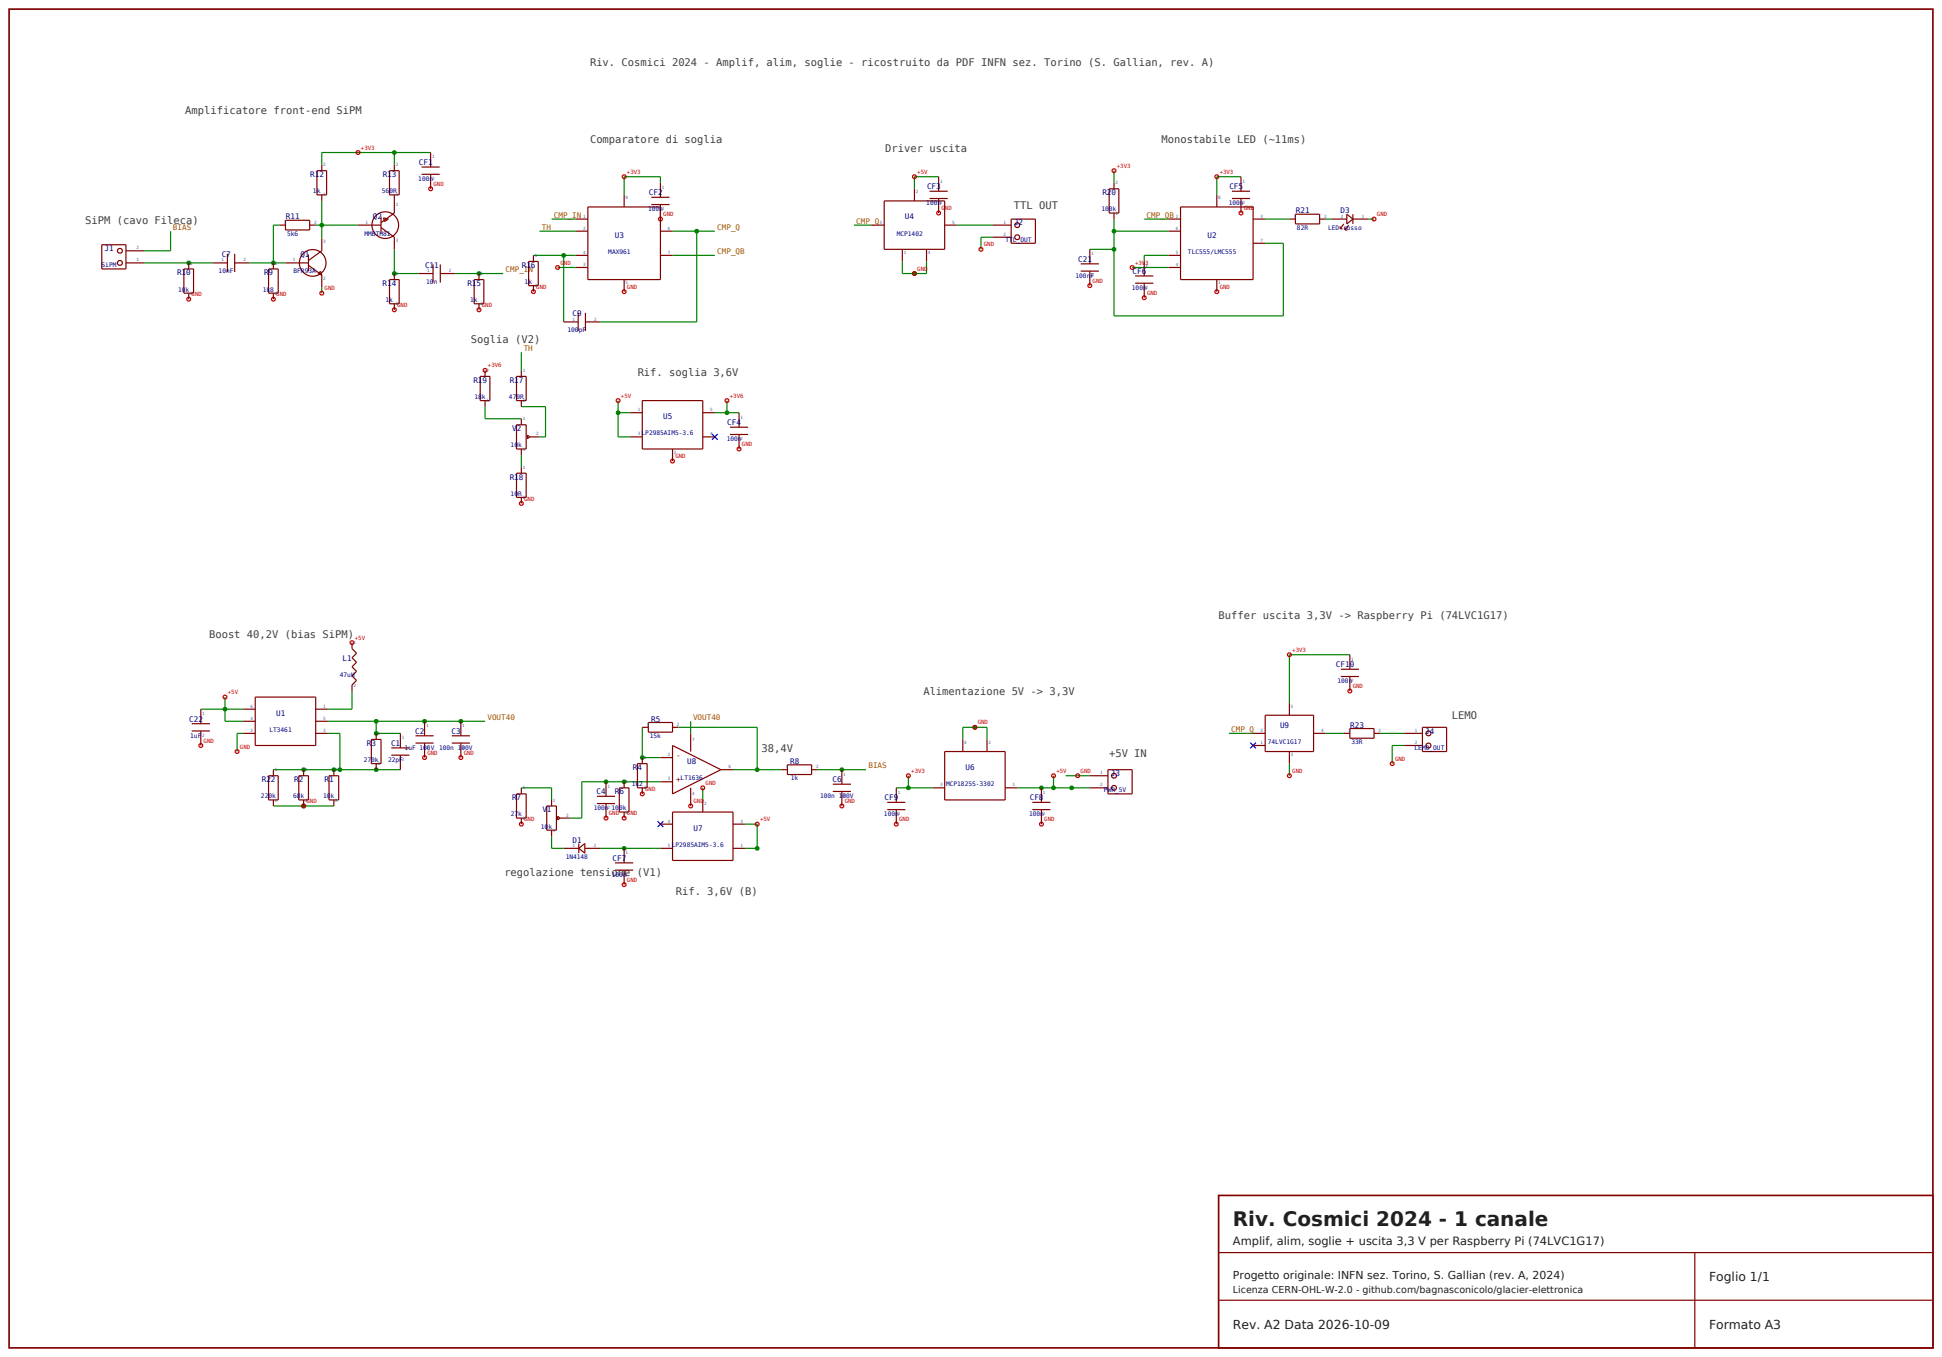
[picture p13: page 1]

Riv. Cosmici 2024 - Amplif, alim, soglie - ricostruito da PDF INFN sez. Torino (S. Gallian, rev. A)

Amplificatore front-end SiPM

Buffer uscita 3,3V -> Raspberry Pi (74LVC1G17)

Amplif, alim, soglie + uscita 3,3 V per Raspberry Pi (74LVC1G17)

Progetto originale: INFN sez. Torino, S. Gallian (rev. A, 2024)
Licenza CERN-OHL-W-2.0 - github.com/bagnasconicolo/glacier-elettronica

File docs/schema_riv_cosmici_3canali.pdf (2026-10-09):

## SiPM (cavo Fileca)

## Amplificatore front-end SiPM

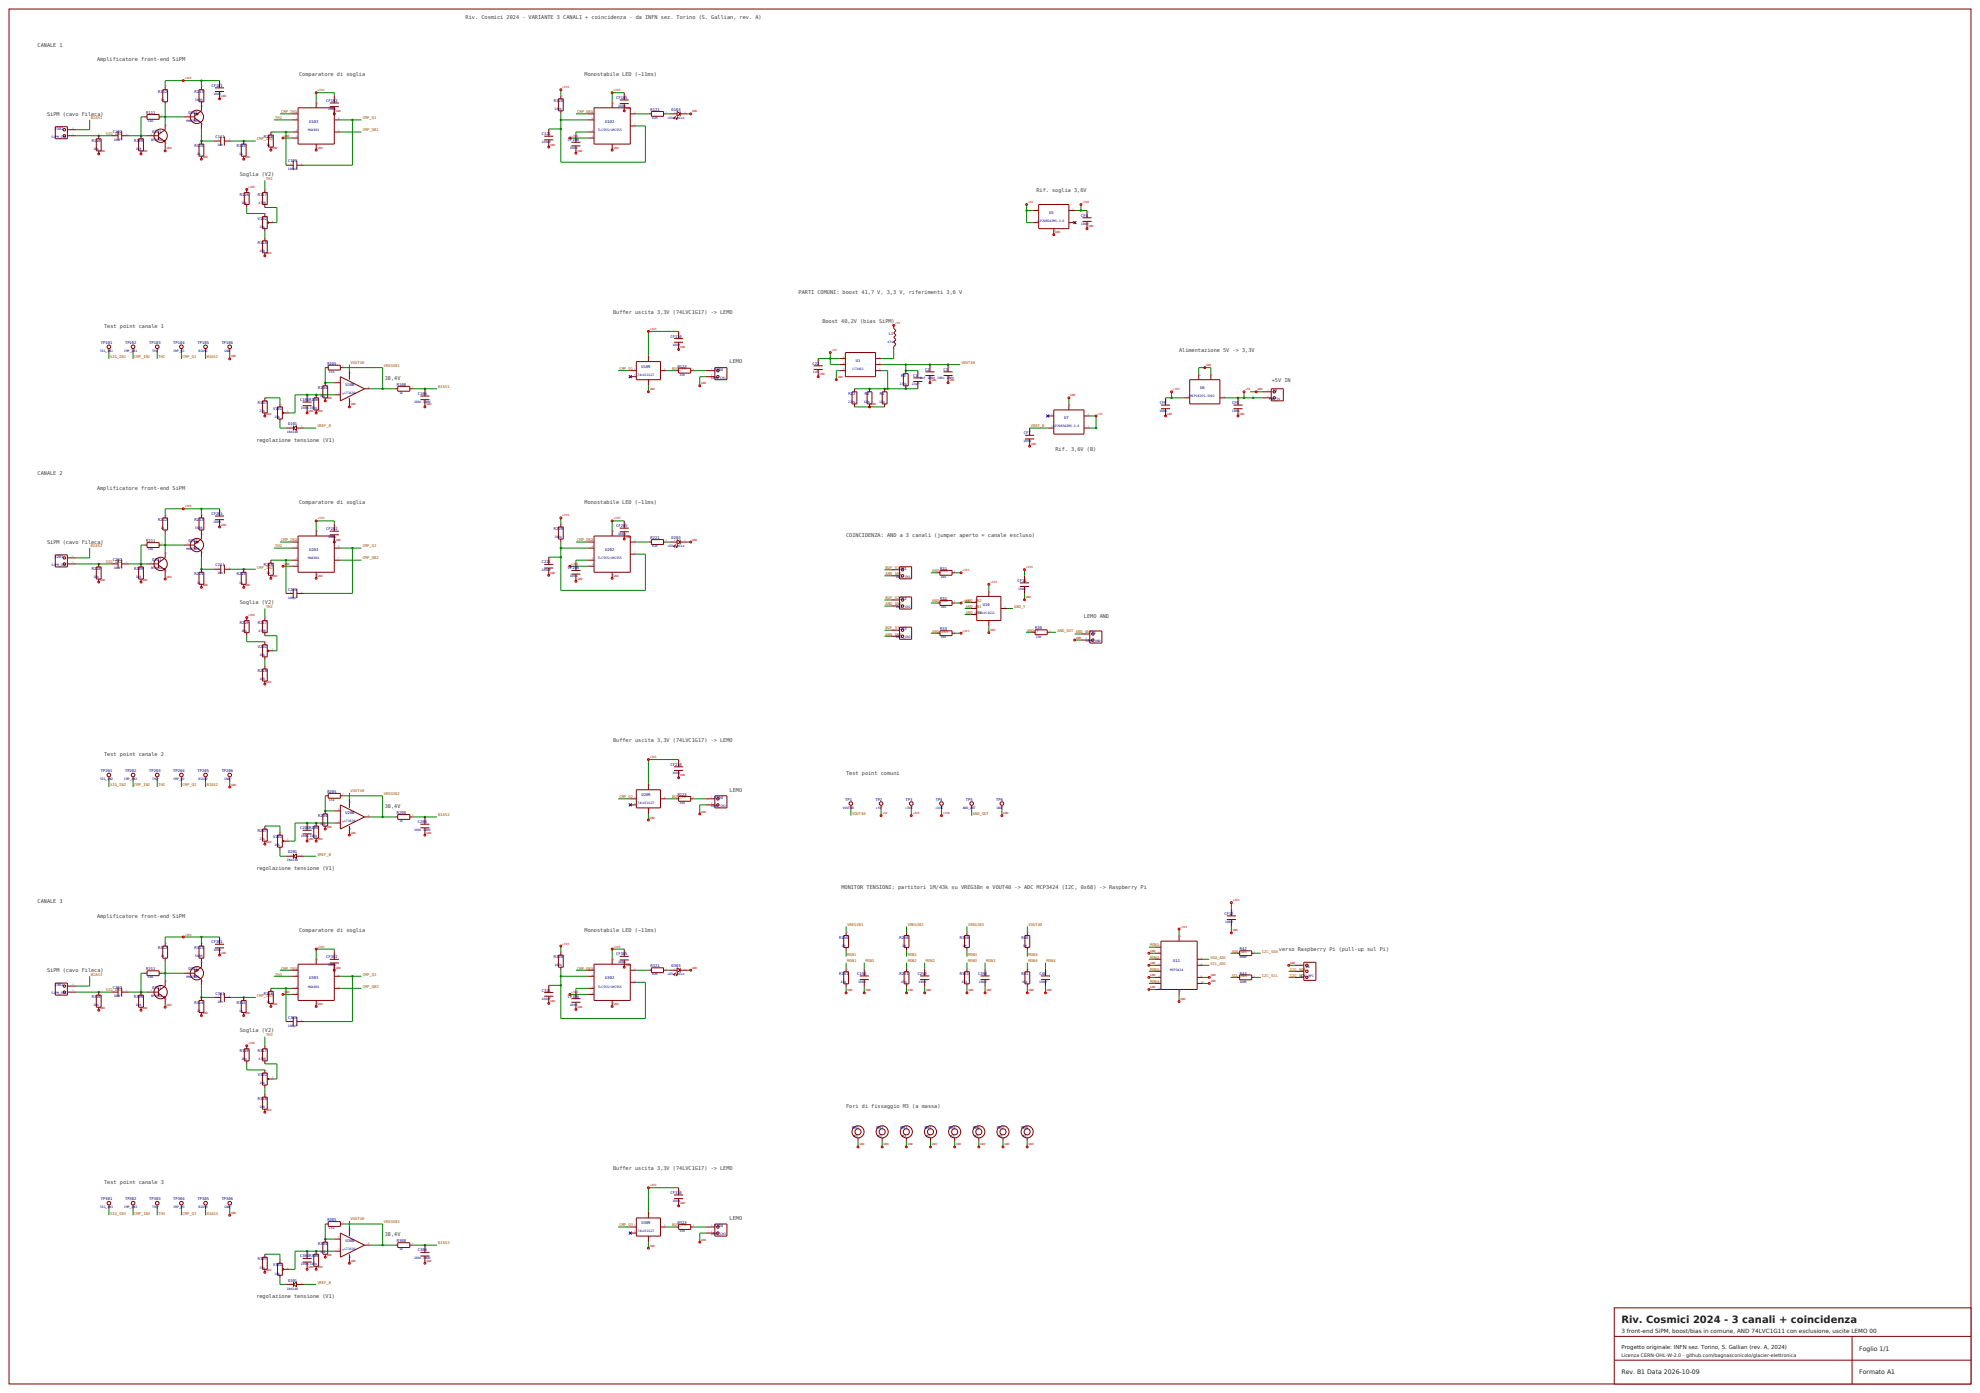
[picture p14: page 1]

Riv. Cosmici 2024 - VARIANTE 3 CANALI + coincidenza - da INFN sez. Torino (S. Gallian, rev. A)

PARTI COMUNI: boost 41,7 V, 3,3 V, riferimenti 3,6 V

Amplificatore front-end SiPM

COINCIDENZA: AND a 3 canali (jumper aperto = canale escluso)

MONITOR TENSIONI: partitori 1M/43k su VREG38n e VOUT40 -> ADC MCP3424 (I2C, 0x68) -> Raspberry Pi

verso Raspberry Pi (pull-up sul Pi)

Fori di fissaggio M3 (a massa)

Riv. Cosmici 2024 - 3 canali + coincidenza

3 front-end SiPM, boost/bias in comune, AND 74LVC1G11 con esclusione, uscite LEMO 00

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

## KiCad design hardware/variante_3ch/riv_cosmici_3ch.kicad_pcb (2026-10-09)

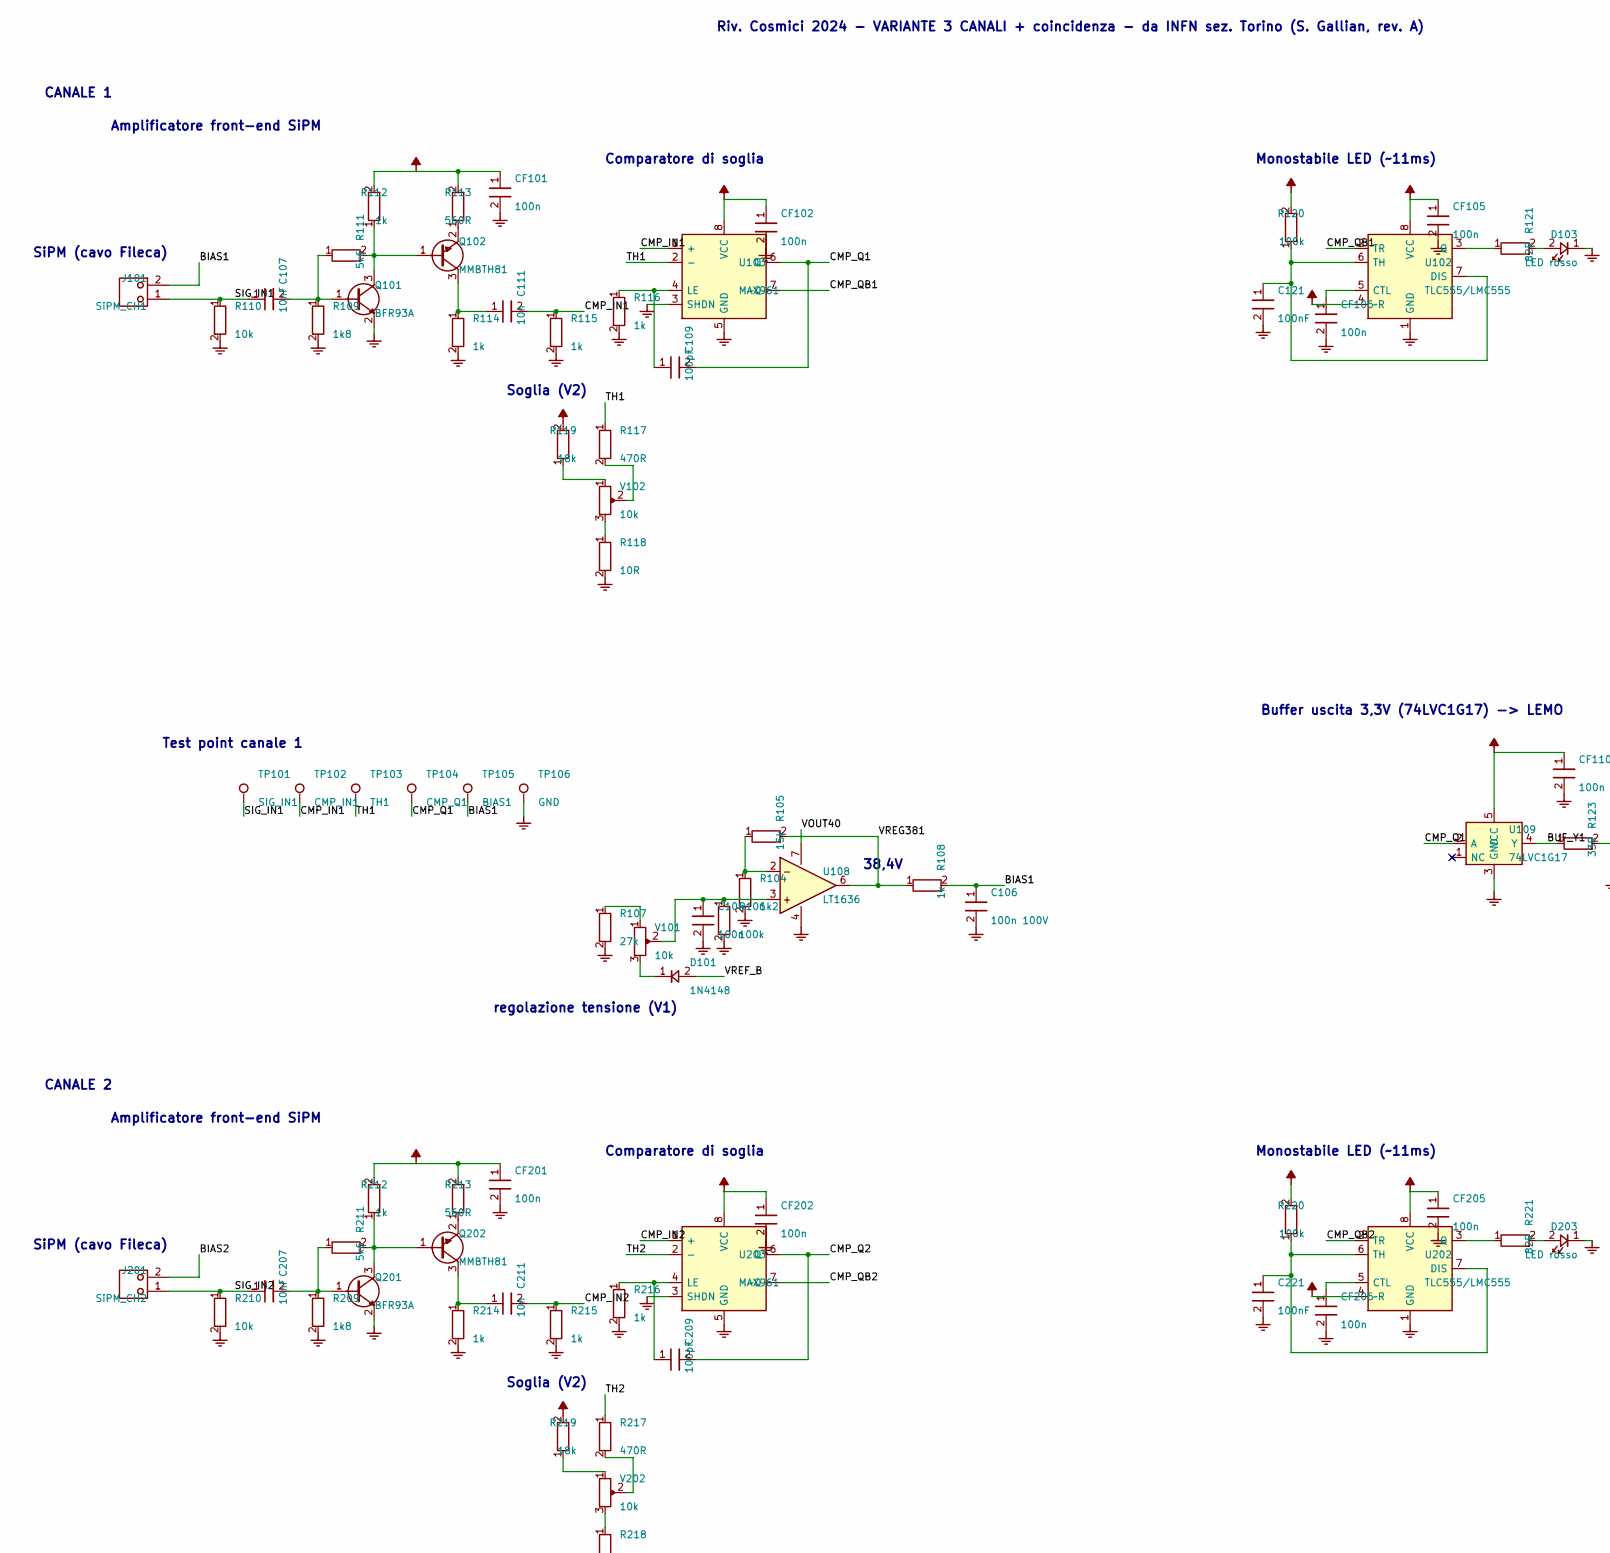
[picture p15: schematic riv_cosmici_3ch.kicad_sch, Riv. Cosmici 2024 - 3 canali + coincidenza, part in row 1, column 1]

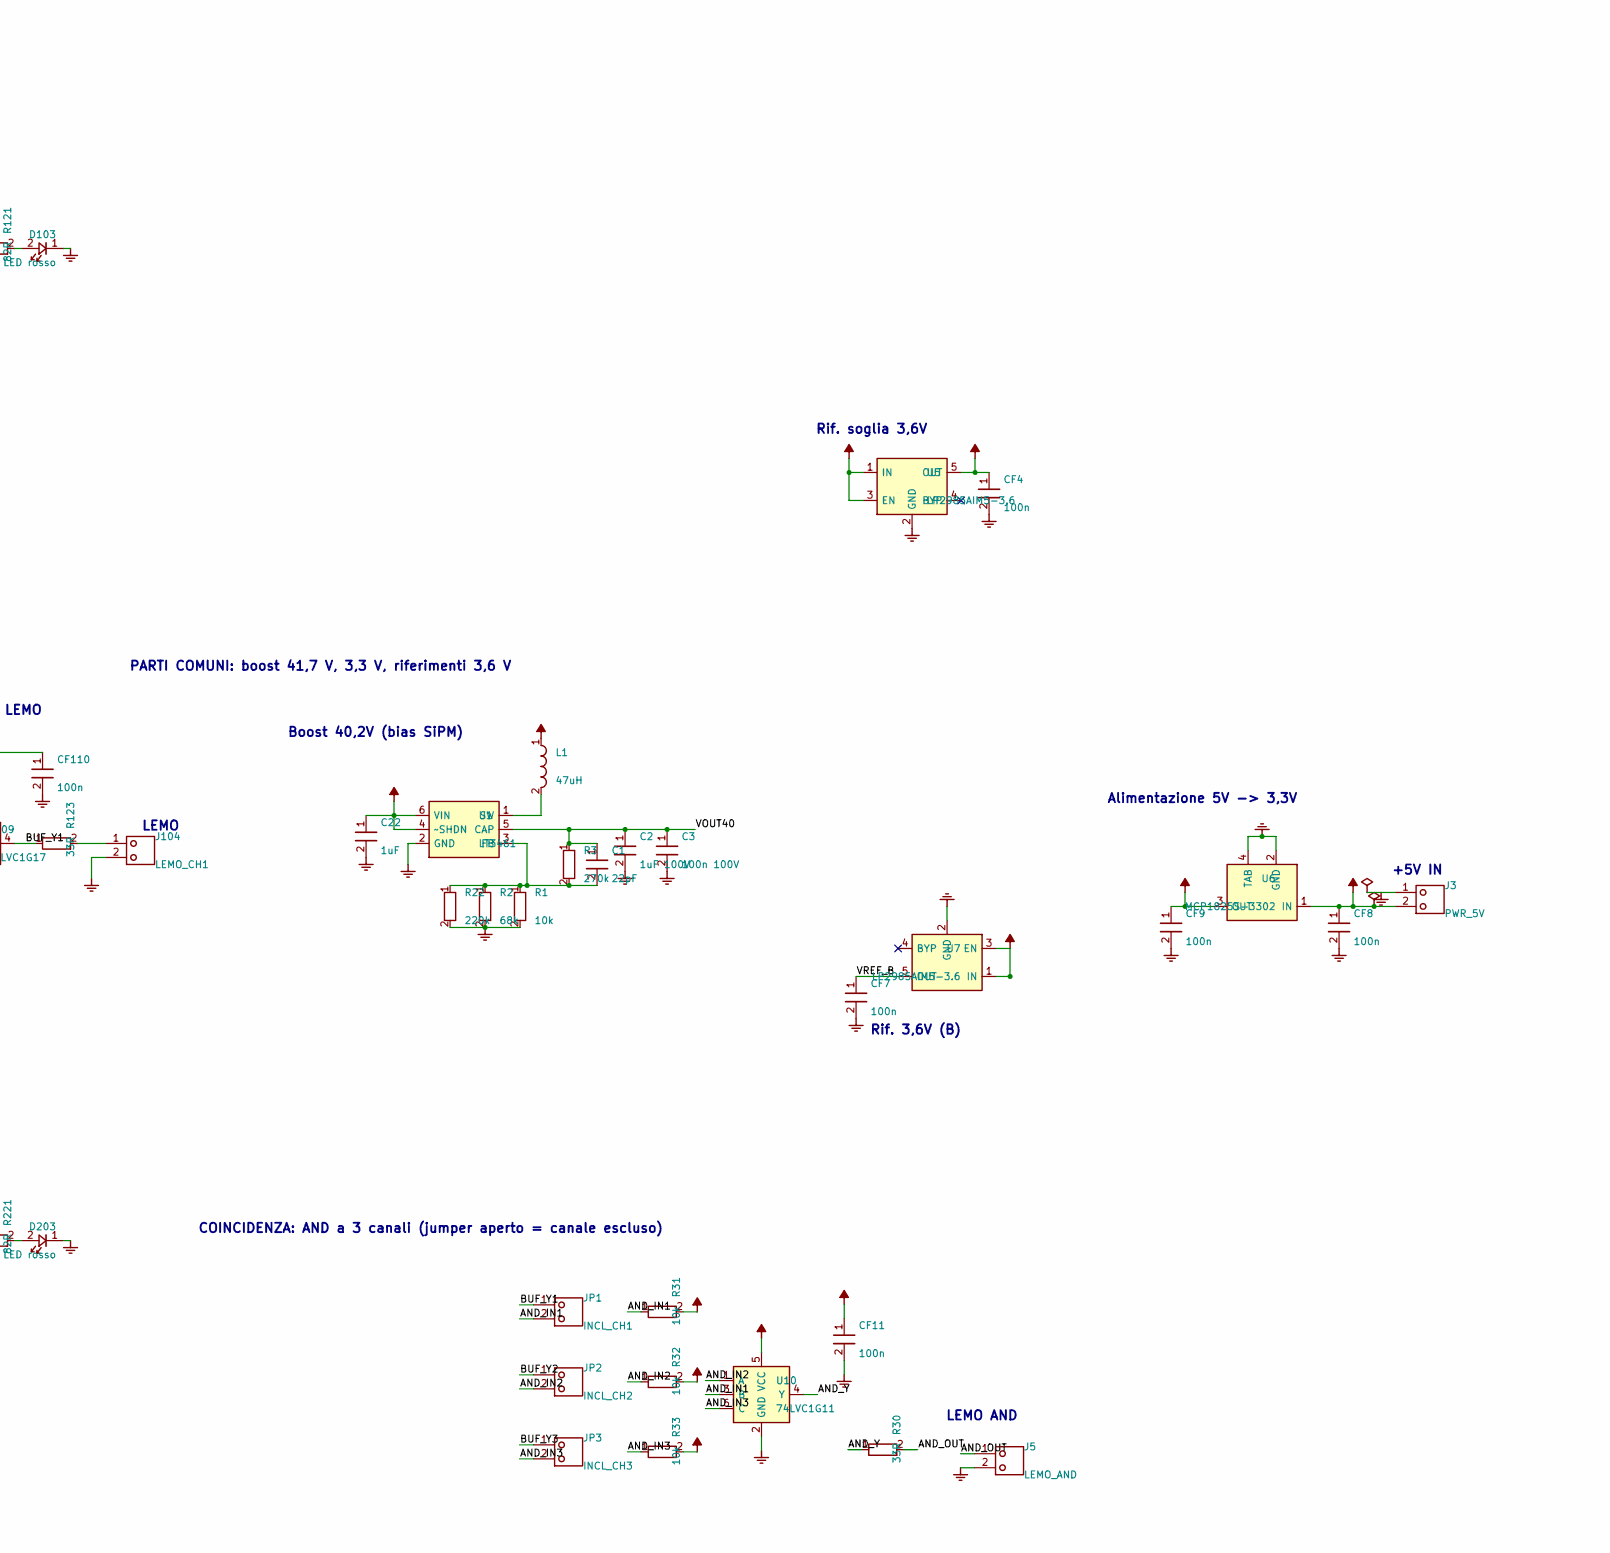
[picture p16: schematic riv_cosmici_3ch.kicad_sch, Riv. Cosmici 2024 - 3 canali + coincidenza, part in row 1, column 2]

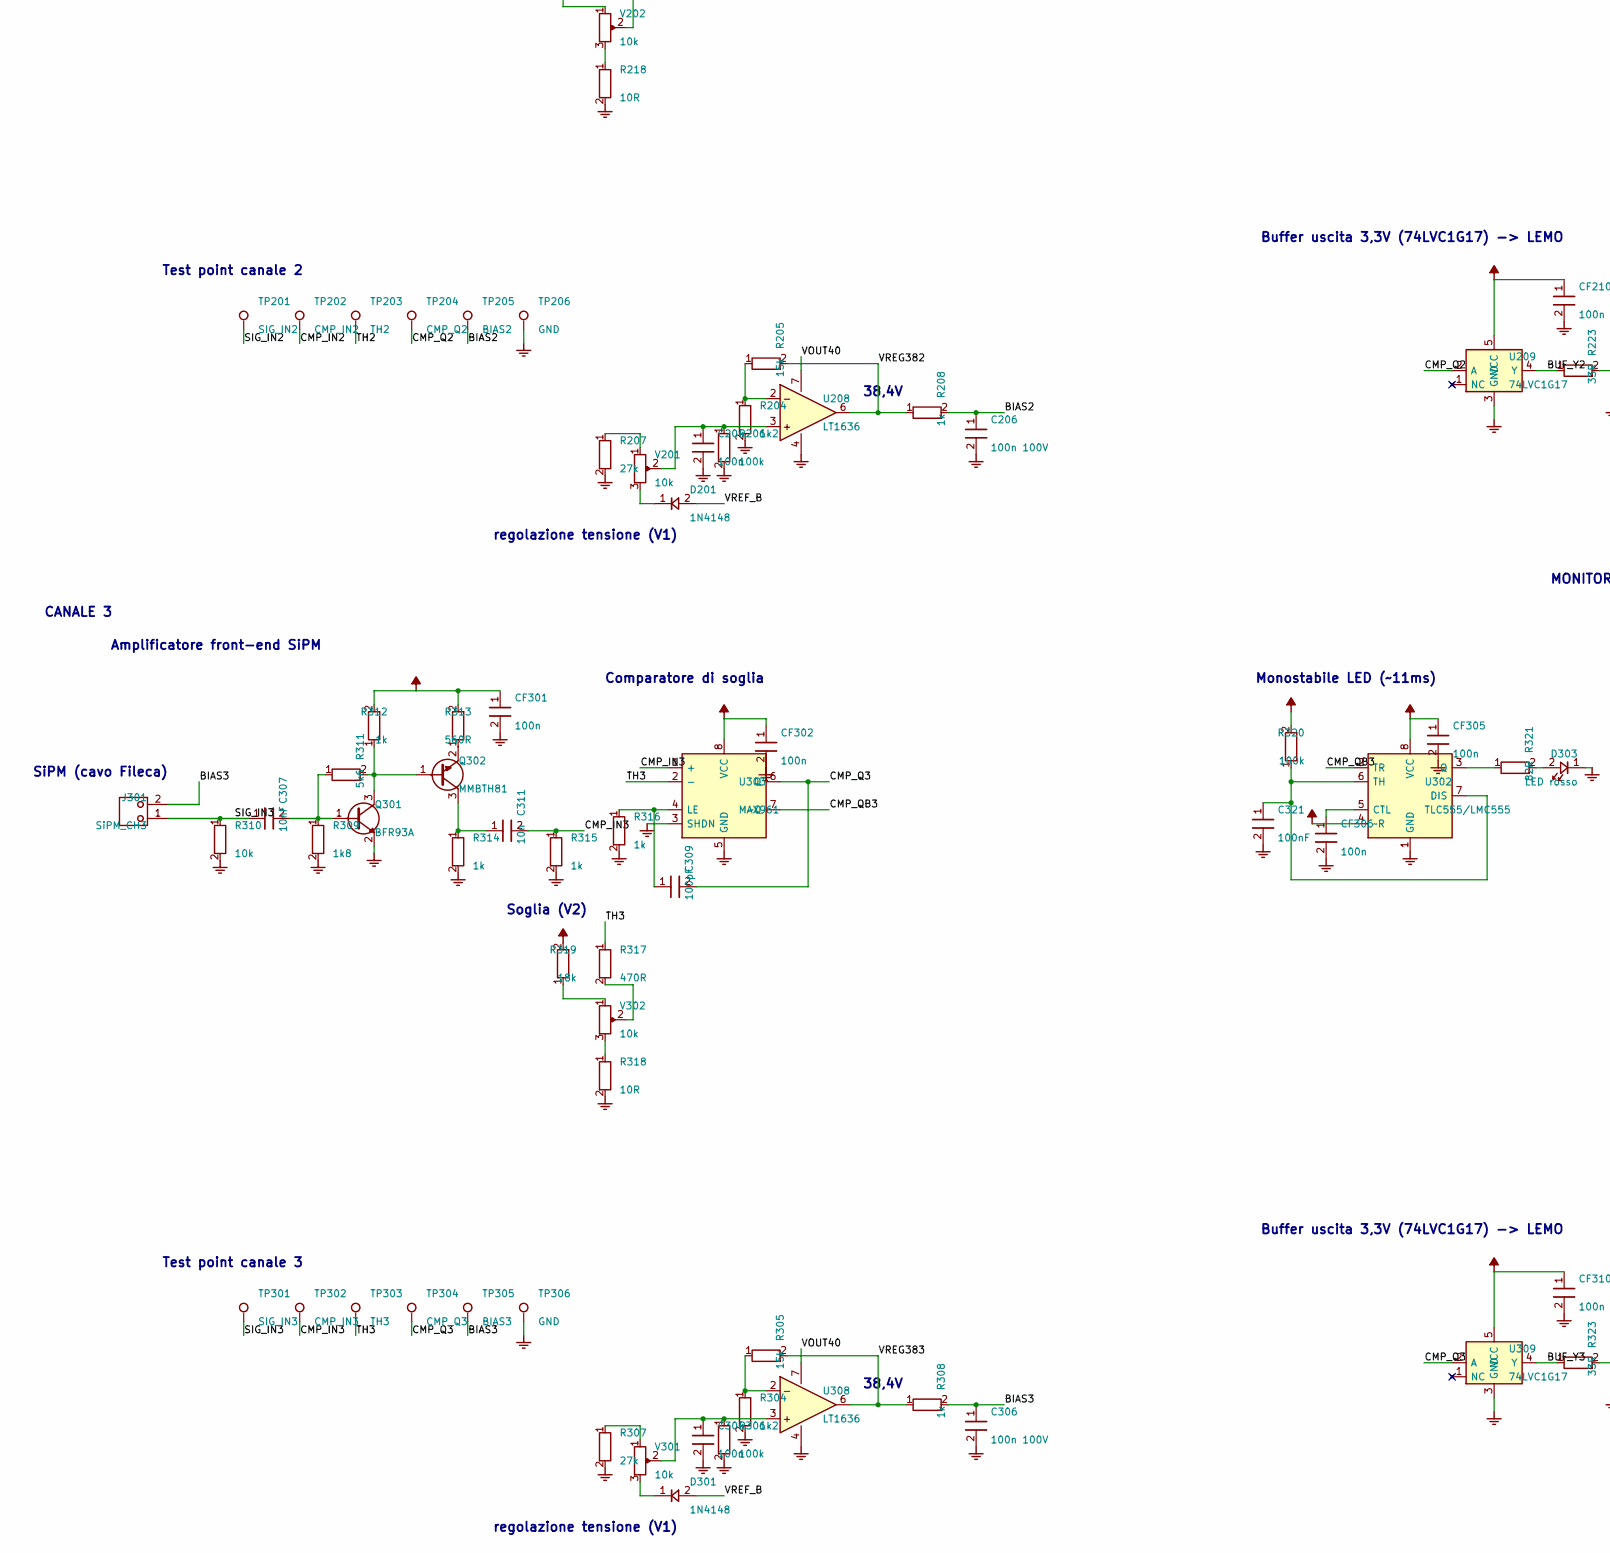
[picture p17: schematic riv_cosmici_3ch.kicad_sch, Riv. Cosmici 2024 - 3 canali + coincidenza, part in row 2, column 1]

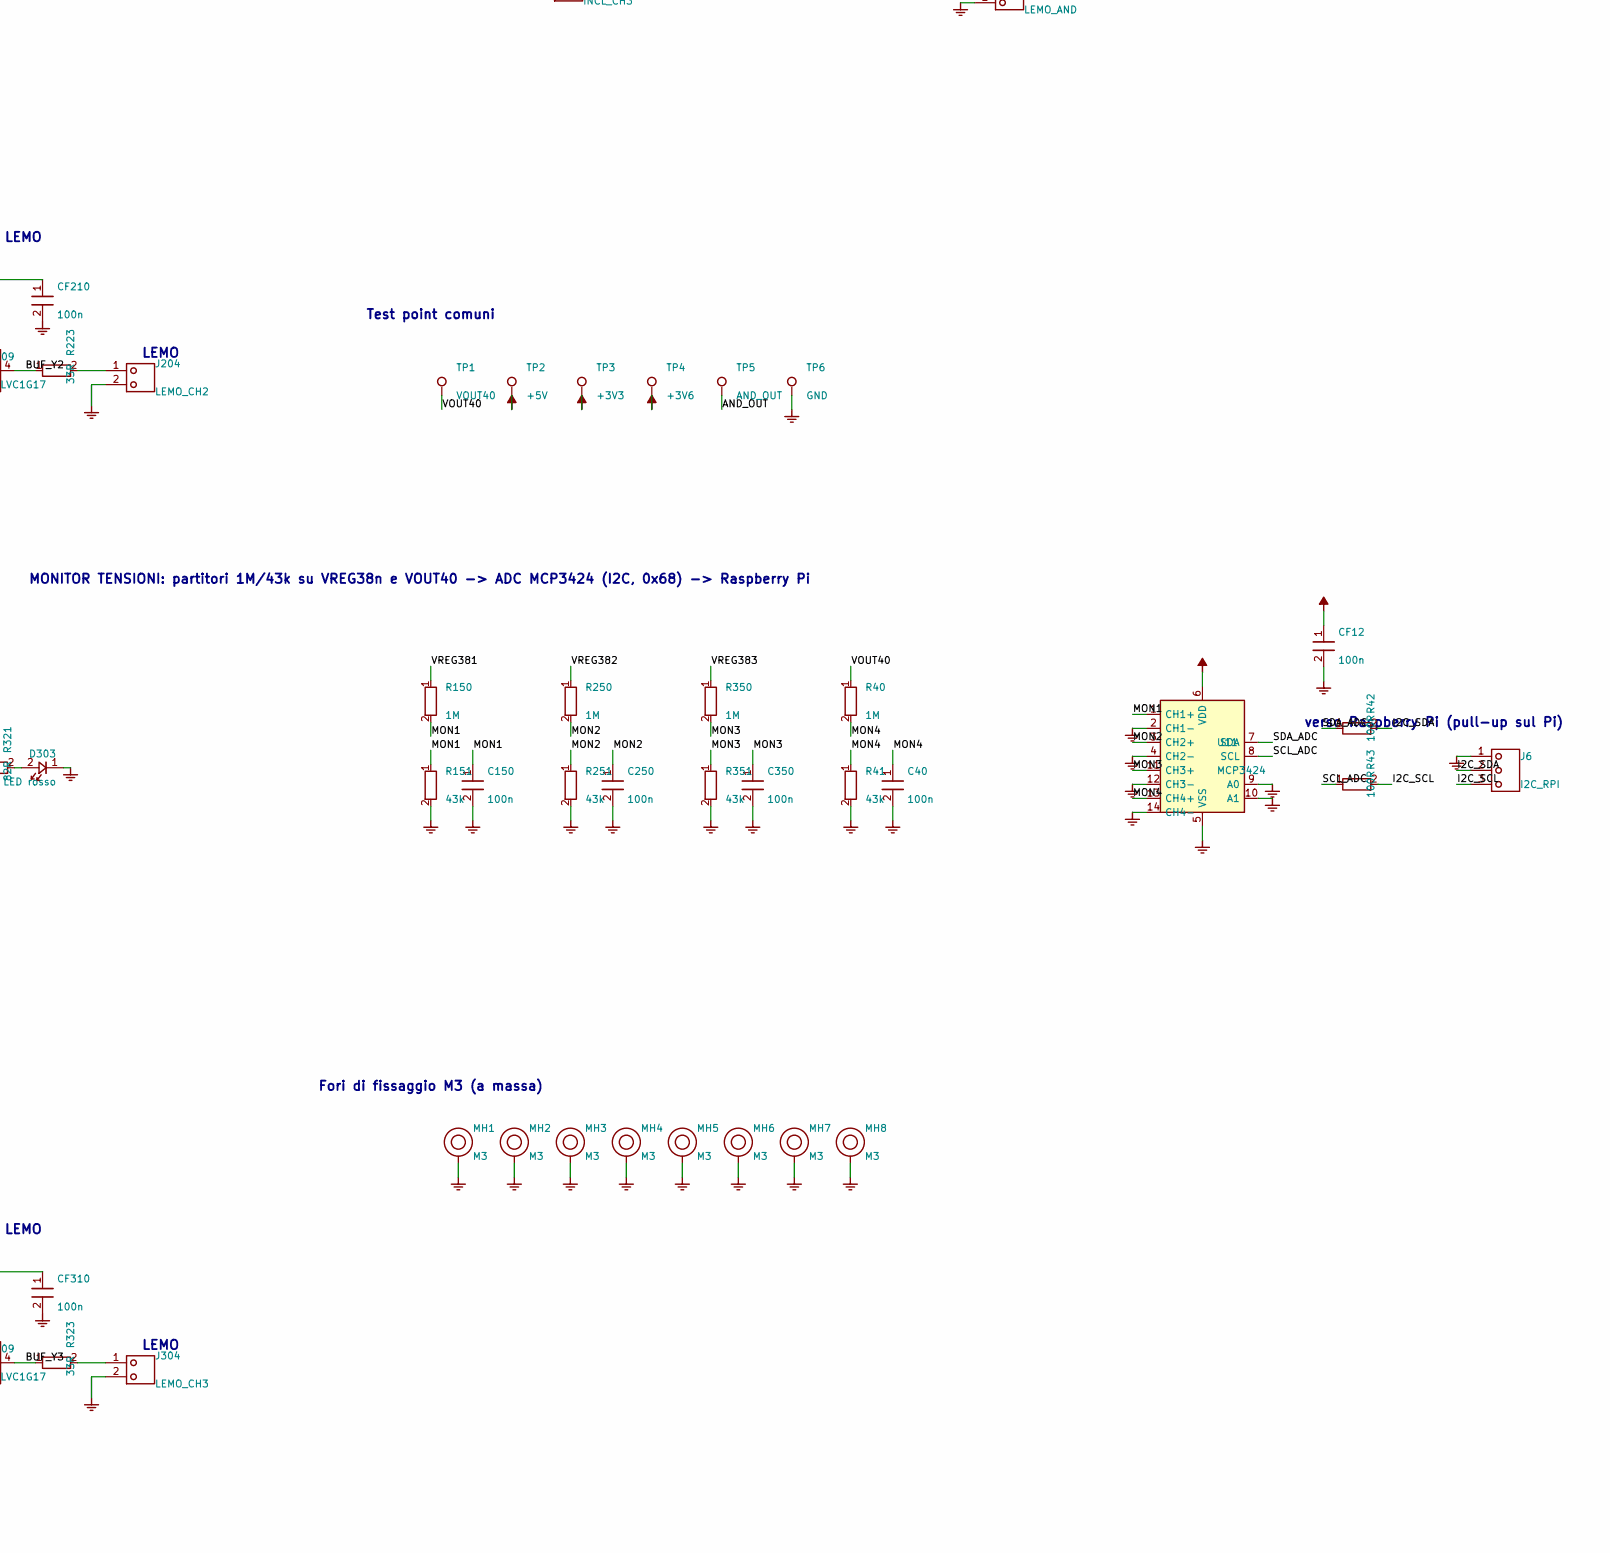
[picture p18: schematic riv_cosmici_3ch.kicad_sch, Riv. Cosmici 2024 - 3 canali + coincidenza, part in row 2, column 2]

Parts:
C1: 22pF; C_0805
C2: 1uF 100V; C_1210
C3, C106, C206, C306: 100n 100V; C_1206
C22: 1uF; C_0805
C40, C104, C150, C204, C250, C304, C350: 100n; C_0805
C107, C207, C307: 10nF; C_0805
C109, C209, C309: 100pF; C_0805
C111, C211, C311: 10n; C_0805
C121, C221, C321: 100nF; C_0805
CF4, CF7, CF8, CF9, CF11, CF12, CF101, CF102, CF105, CF106, CF110, CF201, CF202, CF205, CF206, CF210, CF301, CF302, CF305, CF306, CF310: 100n; C_0805
D101, D201, D301: 1N4148; D_DO35
D103, D203, D303: LED rosso; LED_0805
J3: PWR_5V; HDR1x02
J5: LEMO_AND; LEMO_EPL00
J6: I2C_RPI; HDR1x03
J101: SiPM_CH1; MOLEX_KK_2
J104: LEMO_CH1; LEMO_EPL00
J201: SiPM_CH2; MOLEX_KK_2
J204: LEMO_CH2; LEMO_EPL00
J301: SiPM_CH3; MOLEX_KK_2
J304: LEMO_CH3; LEMO_EPL00
JP1: INCL_CH1; HDR1x02
JP2: INCL_CH2; HDR1x02
JP3: INCL_CH3; HDR1x02
L1: 47uH; L_PWR_5050
MH1, MH2, MH3, MH4, MH5, MH6, MH7, MH8: M3; MH_M3
Q101, Q201, Q301: BFR93A; SOT23
Q102, Q202, Q302: MMBTH81; SOT23
R1, R31, R32, R33, R110, R210, R310: 10k; R_0805
R2: 68k; R_0805
R3: 270k; R_0805
R22: 220k; R_0805
R30, R123, R223, R323: 33R; R_0805
R40, R150, R250, R350: 1M; R_0805
R41, R151, R251, R351: 43k; R_0805
R42, R43: 100R; R_0805
R104, R204, R304: 1k2; R_0805
R105, R205, R305: 15k; R_0805
R106, R120, R206, R220, R306, R320: 100k; R_0805
R107, R207, R307: 27k; R_0805
R108, R112, R114, R115, R116, R208, R212, R214, R215, R216, R308, R312, R314, R315, R316: 1k; R_0805
R109, R209, R309: 1k8; R_0805
R111, R211, R311: 5k6; R_0805
R113, R213, R313: 560R; R_0805
R117, R217, R317: 470R; R_0805
R118, R218, R318: 10R; R_0805
R119, R219, R319: 18k; R_0805
R121, R221, R321: 82R; R_0805
TP1: VOUT40; TP_THT
TP2: +5V; TP_THT
TP3: +3V3; TP_THT
TP4: +3V6; TP_THT
TP5: AND_OUT; TP_THT
TP6, TP106, TP206, TP306: GND; TP_THT
TP101: SIG_IN1; TP_THT
TP102: CMP_IN1; TP_THT
TP103: TH1; TP_THT
TP104: CMP_Q1; TP_THT
TP105: BIAS1; TP_THT
TP201: SIG_IN2; TP_THT
TP202: CMP_IN2; TP_THT
TP203: TH2; TP_THT
TP204: CMP_Q2; TP_THT
TP205: BIAS2; TP_THT
TP301: SIG_IN3; TP_THT
TP302: CMP_IN3; TP_THT
TP303: TH3; TP_THT
TP304: CMP_Q3; TP_THT
TP305: BIAS3; TP_THT
U1: LT3461; SOT23-6
U5, U7: LP2985AIM5-3.6; SOT23-5
U6: MCP1825S-3302; SOT223
U10: 74LVC1G11; SOT23-6
U11: MCP3424; SOIC14
U102, U202, U302: TLC555/LMC555; SOIC8
U103, U203, U303: MAX961; SOIC8
U108, U208, U308: LT1636; SOIC8
U109, U209, U309: 74LVC1G17; SOT23-5
V101, V102, V201, V202, V301, V302: 10k; TRIM_3296W

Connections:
+3V3: CF9.1, CF11.1, CF12.1, CF101.1, CF102.1, CF105.1, CF110.1, CF201.1, CF202.1, CF205.1, CF210.1, CF301.1, CF302.1, CF305.1, CF310.1, R31.2, R32.2, R33.2, R112.2, R113.2, R120.2, R212.2, R213.2, R220.2, R312.2, R313.2, R320.2, TP3.1, U6.3 (OUT), U10.5 (VCC), U11.6 (VDD), U102.4 (~R), U102.8 (VCC), U103.8 (VCC), U109.5 (VCC), U202.4 (~R), U202.8 (VCC), U203.8 (VCC), U209.5 (VCC), U302.4 (~R), U302.8 (VCC), U303.8 (VCC), U309.5 (VCC)
+3V6: CF4.1, R119.2, R219.2, R319.2, TP4.1, U5.5 (OUT)
+5V: C22.1, CF8.1, J3.2, L1.1, TP2.1, U1.4 (~SHDN), U1.6 (VIN), U5.1 (IN), U5.3 (EN), U6.1 (IN), U7.1 (IN), U7.3 (EN)
AND_IN1: JP1.2, R31.1, U10.3 (B)
AND_IN2: JP2.2, R32.1, U10.1 (A)
AND_IN3: JP3.2, R33.1, U10.6 (C)
AND_OUT: J5.1, R30.2, TP5.1
AND_Y: R30.1, U10.4 (Y)
BIAS1: C106.1, J101.2, R108.2, TP105.1
BIAS2: C206.1, J201.2, R208.2, TP205.1
BIAS3: C306.1, J301.2, R308.2, TP305.1
BUF_OUT1: J104.1, R123.2
BUF_OUT2: J204.1, R223.2
BUF_OUT3: J304.1, R323.2
BUF_Y1: JP1.1, R123.1, U109.4 (Y)
BUF_Y2: JP2.1, R223.1, U209.4 (Y)
BUF_Y3: JP3.1, R323.1, U309.4 (Y)
CMP_IN1: C111.2, R115.1, TP102.1, U103.1 (+)
CMP_IN2: C211.2, R215.1, TP202.1, U203.1 (+)
CMP_IN3: C311.2, R315.1, TP302.1, U303.1 (+)
CMP_Q1: C109.2, TP104.1, U103.6 (Q), U109.2 (A)
CMP_Q2: C209.2, TP204.1, U203.6 (Q), U209.2 (A)
CMP_Q3: C309.2, TP304.1, U303.6 (Q), U309.2 (A)
CMP_QB1: U102.2 (TR), U103.7 (~Q)
CMP_QB2: U202.2 (TR), U203.7 (~Q)
CMP_QB3: U302.2 (TR), U303.7 (~Q)
CTL5551: CF106.1, U102.5 (CTL)
CTL5552: CF206.1, U202.5 (CTL)
CTL5553: CF306.1, U302.5 (CTL)
FB: C1.2, R1.1, R2.1, R3.2, R22.1, U1.3 (FB)
GND: C2.2, C3.2, C22.2, C40.2, C104.2, C106.2, C121.2, C150.2, C204.2, C206.2, C221.2, C250.2, C304.2, C306.2, C321.2, C350.2, CF4.2, CF7.2, CF8.2, CF9.2, CF11.2, CF12.2, CF101.2, CF102.2, CF105.2, CF106.2, CF110.2, CF201.2, CF202.2, CF205.2, CF206.2, CF210.2, CF301.2, CF302.2, CF305.2, CF306.2, CF310.2, D103.1 (K), D203.1 (K), D303.1 (K), J3.1, J5.2, J6.1, J104.2, J204.2, J304.2, MH1.1, MH2.1, MH3.1, MH4.1, MH5.1, MH6.1, MH7.1, MH8.1, Q101.2 (E), Q201.2 (E), Q301.2 (E), R1.2, R2.2, R22.2, R41.2, R104.2, R106.2, R107.2, R109.2, R110.2, R114.2, R115.2, R116.2, R118.2, R151.2, R204.2, R206.2, R207.2, R209.2, R210.2, R214.2, R215.2, R216.2, R218.2, R251.2, R304.2, R306.2, R307.2, R309.2, R310.2, R314.2, R315.2, R316.2, R318.2, R351.2, TP6.1, TP106.1, TP206.1, TP306.1, U1.2 (GND), U5.2 (GND), U6.2 (GND), U6.4 (TAB), U7.2 (GND), U10.2 (GND), U11.2 (CH1-), U11.4 (CH2-), U11.5 (VSS), U11.9 (A0), U11.10 (A1), U11.12 (CH3-), U11.14 (CH4-), U102.1 (GND), U103.3 (SHDN), U103.5 (GND), U108.4 (V-), U109.3 (GND), U202.1 (GND), U203.3 (SHDN), U203.5 (GND), U208.4 (V-), U209.3 (GND), U302.1 (GND), U303.3 (SHDN), U303.5 (GND), U308.4 (V-), U309.3 (GND)
I2C_SCL: J6.3, R43.2
I2C_SDA: J6.2, R42.2
INV1: R104.1, R105.1, U108.2 (-)
INV2: R204.1, R205.1, U208.2 (-)
INV3: R304.1, R305.1, U308.2 (-)
LE1: C109.1, R116.1, U103.4 (LE)
LE2: C209.1, R216.1, U203.4 (LE)
LE3: C309.1, R316.1, U303.4 (LE)
LED_A1: R121.1, U102.3 (Q)
LED_A2: R221.1, U202.3 (Q)
LED_A3: R321.1, U302.3 (Q)
LED_K1: D103.2 (A), R121.2
LED_K2: D203.2 (A), R221.2
LED_K3: D303.2 (A), R321.2
MON1: C150.1, R150.2, R151.1, U11.1 (CH1+)
MON2: C250.1, R250.2, R251.1, U11.3 (CH2+)
MON3: C350.1, R350.2, R351.1, U11.11 (CH3+)
MON4: C40.1, R40.2, R41.1, U11.13 (CH4+)
Q1B1: C107.2, Q101.1 (B), R109.1, R111.1
Q1B2: C207.2, Q201.1 (B), R209.1, R211.1
Q1B3: C307.2, Q301.1 (B), R309.1, R311.1
Q1C1: Q101.3 (C), Q102.1 (B), R111.2, R112.1
Q1C2: Q201.3 (C), Q202.1 (B), R211.2, R212.1
Q1C3: Q301.3 (C), Q302.1 (B), R311.2, R312.1
Q2C1: C111.1, Q102.3 (C), R114.1
Q2C2: C211.1, Q202.3 (C), R214.1
Q2C3: C311.1, Q302.3 (C), R314.1
Q2E1: Q102.2 (E), R113.1
Q2E2: Q202.2 (E), R213.1
Q2E3: Q302.2 (E), R313.1
SCL_ADC: R43.1, U11.8 (SCL)
SDA_ADC: R42.1, U11.7 (SDA)
SIG_IN1: C107.1, J101.1, R110.1, TP101.1
SIG_IN2: C207.1, J201.1, R210.1, TP201.1
SIG_IN3: C307.1, J301.1, R310.1, TP301.1
SW: L1.2, U1.1 (SW)
T5551: C121.1, R120.1, U102.6 (TH), U102.7 (DIS)
T5552: C221.1, R220.1, U202.6 (TH), U202.7 (DIS)
T5553: C321.1, R320.1, U302.6 (TH), U302.7 (DIS)
TH1: R117.1, TP103.1, U103.2 (-)
TH2: R217.1, TP203.1, U203.2 (-)
TH3: R317.1, TP303.1, U303.2 (-)
TH_HI1: R119.1, V102.1
TH_HI2: R219.1, V202.1
TH_HI3: R319.1, V302.1
TH_LO1: R118.1, V102.3
TH_LO2: R218.1, V202.3
TH_LO3: R318.1, V302.3
TH_W1: R117.2, V102.2 (W)
TH_W2: R217.2, V202.2 (W)
TH_W3: R317.2, V302.2 (W)
VADJ_HI1: D101.1 (K), V101.3
VADJ_HI2: D201.1 (K), V201.3
VADJ_HI3: D301.1 (K), V301.3
VADJ_LO1: R107.1, V101.1
VADJ_LO2: R207.1, V201.1
VADJ_LO3: R307.1, V301.1
VOUT40: C1.1, C2.1, C3.1, R3.1, R40.1, TP1.1, U1.5 (CAP), U108.7 (V+), U208.7 (V+), U308.7 (V+)
VREF_B: CF7.1, D101.2 (A), D201.2 (A), D301.2 (A), U7.5 (OUT)
VREG381: R105.2, R108.1, R150.1, U108.6
VREG382: R205.2, R208.1, R250.1, U208.6
VREG383: R305.2, R308.1, R350.1, U308.6
VSET1: C104.1, R106.1, U108.3 (+), V101.2 (W)
VSET2: C204.1, R206.1, U208.3 (+), V201.2 (W)
VSET3: C304.1, R306.1, U308.3 (+), V301.2 (W)

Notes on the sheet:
SiPM (cavo Fileca)
Amplificatore front-end SiPM
Comparatore di soglia
Soglia (V2)
Monostabile LED (~11ms)
38,4V
regolazione tensione (V1)
Buffer uscita 3,3V (74LVC1G17) -> LEMO
LEMO
CANALE 1
Test point canale 1
CANALE 2
Test point canale 2
CANALE 3
Test point canale 3
Boost 40,2V (bias SiPM)
+5V IN
Alimentazione 5V -> 3,3V
Rif. soglia 3,6V
Rif. 3,6V (B)
PARTI COMUNI: boost 41,7 V, 3,3 V, riferimenti 3,6 V
COINCIDENZA: AND a 3 canali (jumper aperto = canale escluso)
LEMO AND
Test point comuni
MONITOR TENSIONI: partitori 1M/43k su VREG38n e VOUT40 -> ADC MCP3424 (I2C, 0x68) -> Raspberry Pi
verso Raspberry Pi (pull-up sul Pi)
Fori di fissaggio M3 (a massa)
Riv. Cosmici 2024 - VARIANTE 3 CANALI + coincidenza - da INFN sez. Torino (S. Gallian, rev. A)

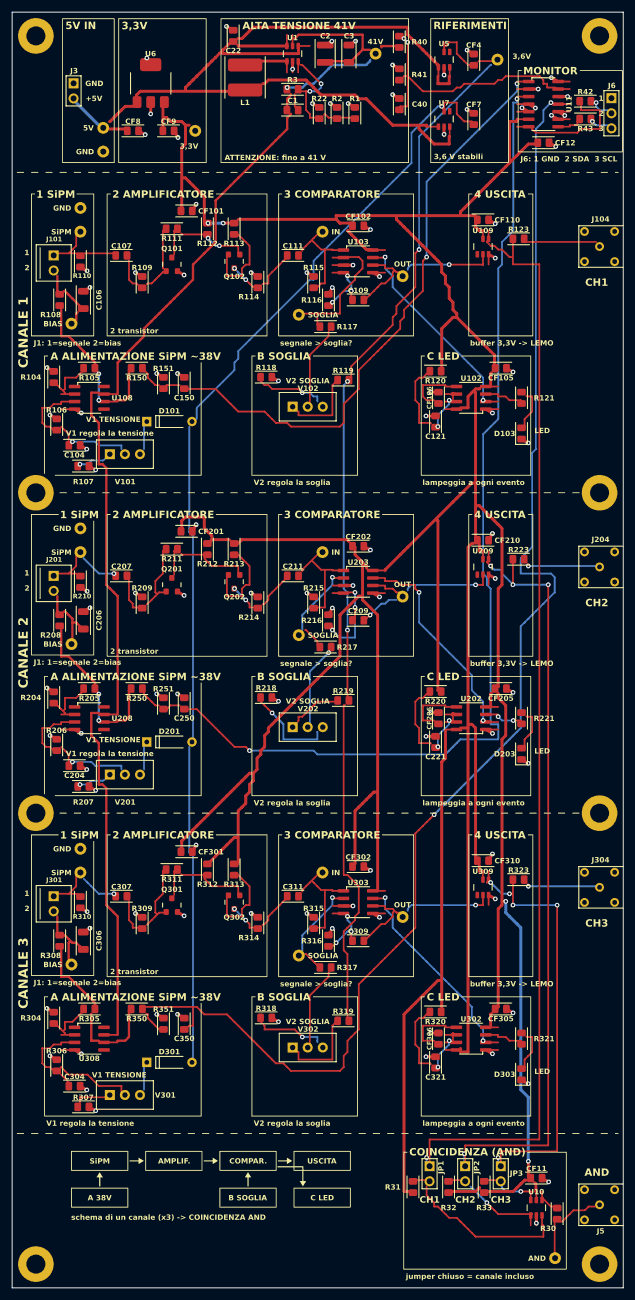
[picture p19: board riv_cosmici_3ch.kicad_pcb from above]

Board: 2 copper layers, 103.0 x 215.0 mm, 203 parts (0 on the bottom side), 96 nets.

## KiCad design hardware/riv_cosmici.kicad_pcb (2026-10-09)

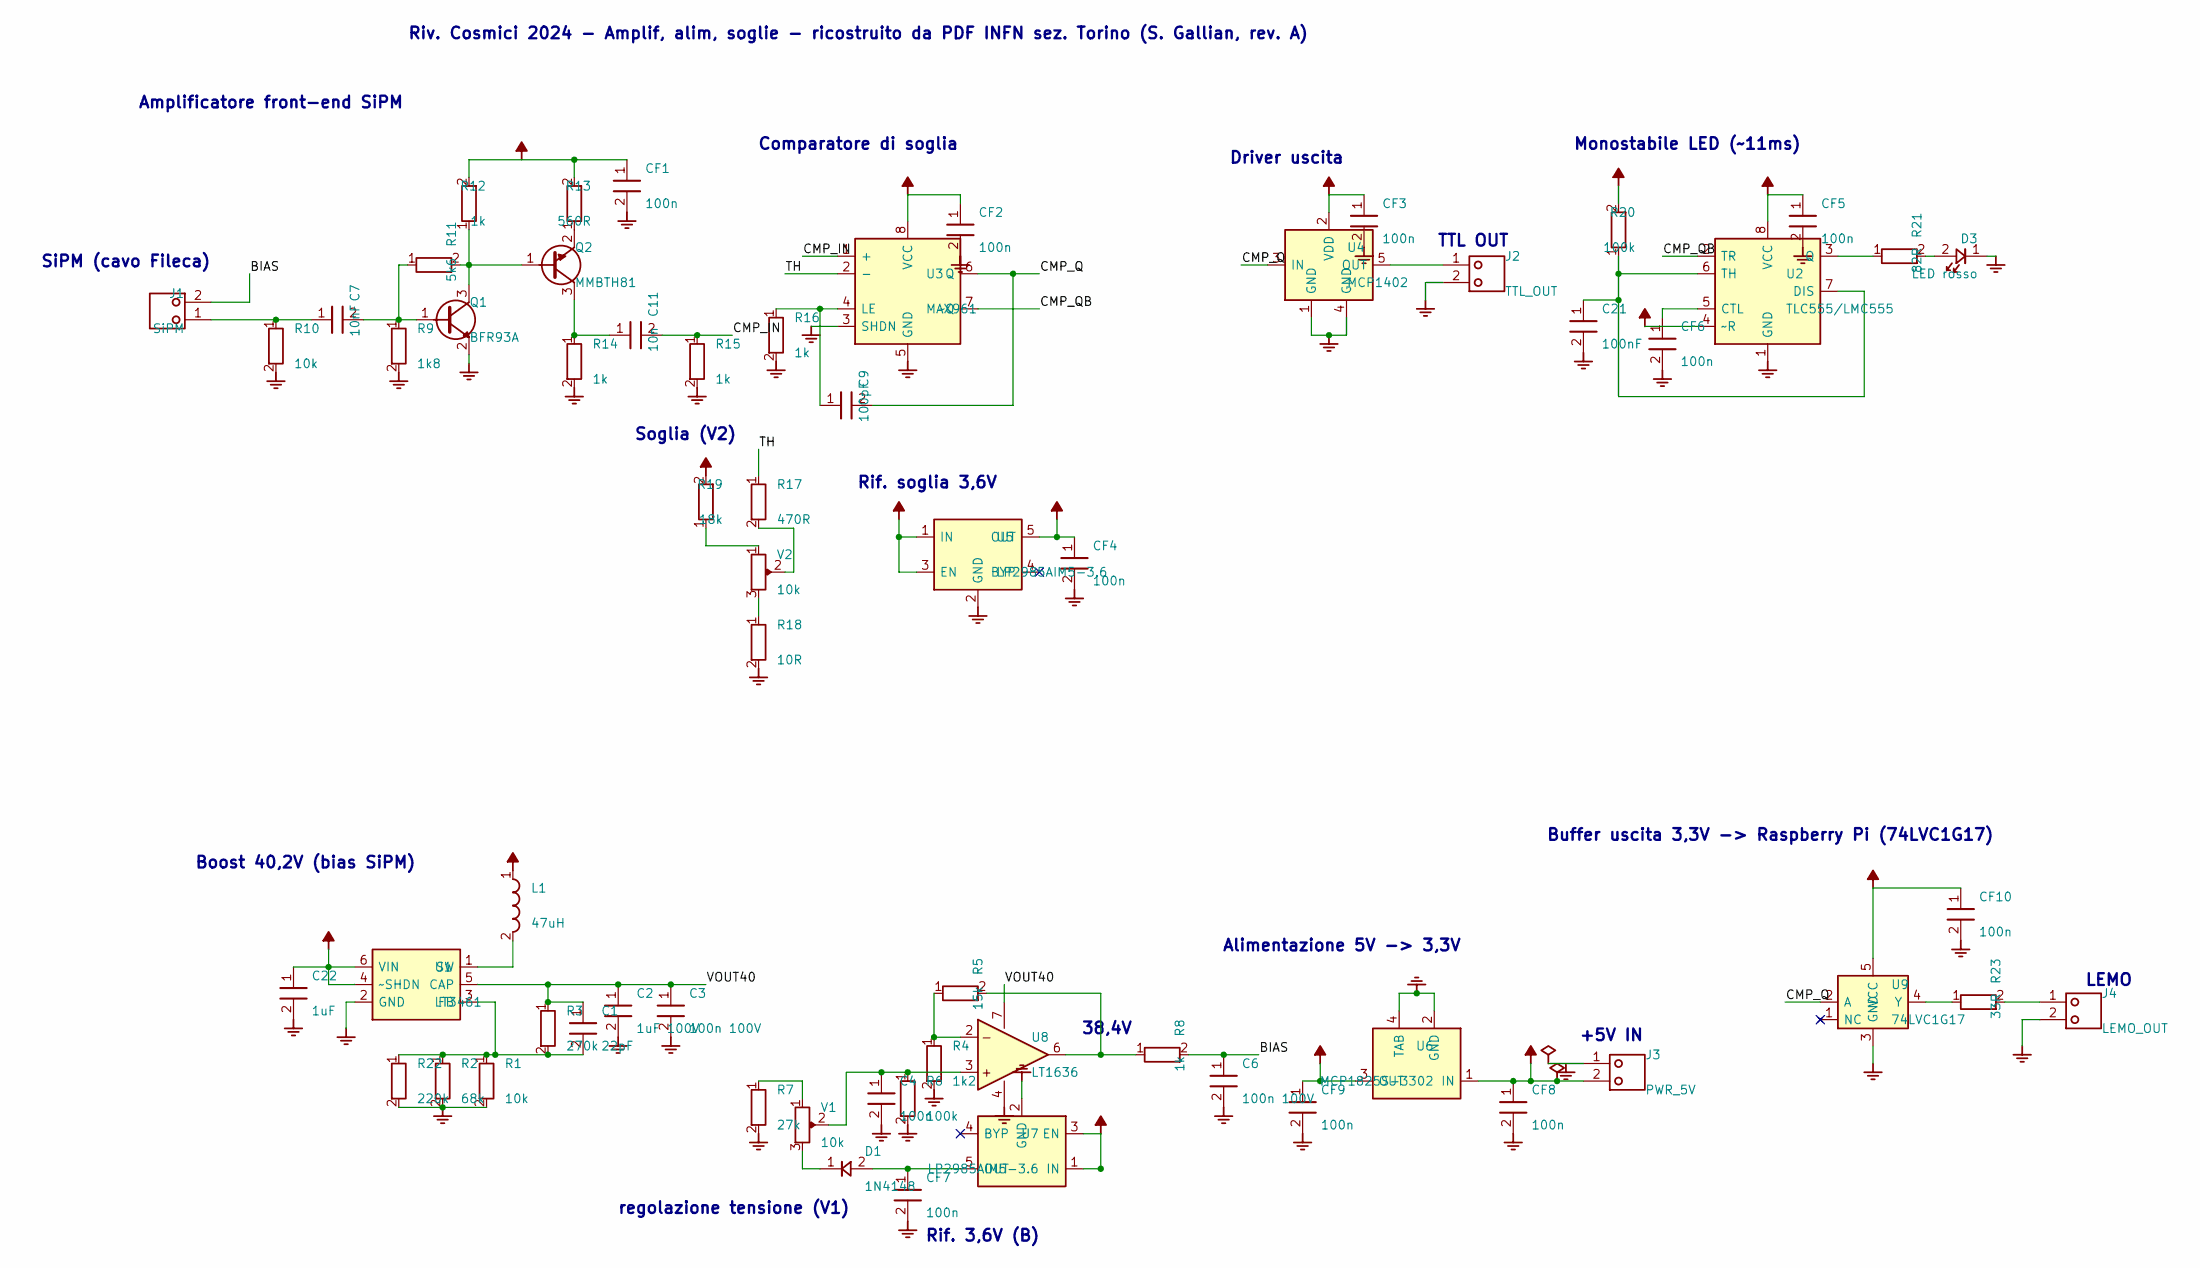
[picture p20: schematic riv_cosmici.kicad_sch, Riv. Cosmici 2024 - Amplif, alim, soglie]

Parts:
C1: 22pF; C_0805
C2: 1uF 100V; C_1210
C3, C6: 100n 100V; C_1206
C4: 100n; C_0805
C7: 10nF; C_0805
C9: 100pF; C_0805
C11: 10n; C_0805
C21: 100nF; C_0805
C22: 1uF; C_0805
CF1, CF2, CF3, CF4, CF5, CF6, CF7, CF8, CF9, CF10: 100n; C_0805
D1: 1N4148; D_DO35
D3: LED rosso; LED_0805
J1: SiPM; HDR1x02
J2: TTL_OUT; HDR1x02
J3: PWR_5V; HDR1x02
J4: LEMO_OUT; HDR1x02
L1: 47uH; L_PWR_5050
Q1: BFR93A; SOT23
Q2: MMBTH81; SOT23
R1, R10: 10k; R_0805
R2: 68k; R_0805
R3: 270k; R_0805
R4: 1k2; R_0805
R5: 15k; R_0805
R6, R20: 100k; R_0805
R7: 27k; R_0805
R8, R12, R14, R15, R16: 1k; R_0805
R9: 1k8; R_0805
R11: 5k6; R_0805
R13: 560R; R_0805
R17: 470R; R_0805
R18: 10R; R_0805
R19: 18k; R_0805
R21: 82R; R_0805
R22: 220k; R_0805
R23: 33R; R_0805
U1: LT3461; SOT23-6
U2: TLC555/LMC555; SOIC8
U3: MAX961; SOIC8
U4: MCP1402; SOT23-5
U5, U7: LP2985AIM5-3.6; SOT23-5
U6: MCP1825S-3302; SOT223
U8: LT1636; SOIC8
U9: 74LVC1G17; SOT23-5
V1, V2: 10k; TRIM_3296W

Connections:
+3V3: CF1.1, CF2.1, CF5.1, CF9.1, CF10.1, R12.2, R13.2, R20.2, U2.4 (~R), U2.8 (VCC), U3.8 (VCC), U6.3 (OUT), U9.5 (VCC)
+3V6: CF4.1, R19.2, U5.5 (OUT)
+5V: C22.1, CF3.1, CF8.1, J3.2, L1.1, U1.4 (~SHDN), U1.6 (VIN), U4.2 (VDD), U5.1 (IN), U5.3 (EN), U6.1 (IN), U7.1 (IN), U7.3 (EN)
BIAS: C6.1, J1.2, R8.2
BUF_OUT: J4.1, R23.2
BUF_Y: R23.1, U9.4 (Y)
CMP_IN: C11.2, R15.1, U3.1 (+)
CMP_Q: C9.2, U3.6 (Q), U4.3 (IN), U9.2 (A)
CMP_QB: U2.2 (TR), U3.7 (~Q)
CTL555: CF6.1, U2.5 (CTL)
FB: C1.2, R1.1, R2.1, R3.2, R22.1, U1.3 (FB)
GND: C2.2, C3.2, C4.2, C6.2, C21.2, C22.2, CF1.2, CF2.2, CF3.2, CF4.2, CF5.2, CF6.2, CF7.2, CF8.2, CF9.2, CF10.2, D3.1 (K), J2.2, J3.1, J4.2, Q1.2 (E), R1.2, R2.2, R4.2, R6.2, R7.2, R9.2, R10.2, R14.2, R15.2, R16.2, R18.2, R22.2, U1.2 (GND), U2.1 (GND), U3.3 (SHDN), U3.5 (GND), U4.1 (GND), U4.4 (GND), U5.2 (GND), U6.2 (GND), U6.4 (TAB), U7.2 (GND), U8.4 (V-), U9.3 (GND)
INV: R4.1, R5.1, U8.2 (-)
LE: C9.1, R16.1, U3.4 (LE)
LED_A: R21.1, U2.3 (Q)
LED_K: D3.2 (A), R21.2
Q1B: C7.2, Q1.1 (B), R9.1, R11.1
Q1C: Q1.3 (C), Q2.1 (B), R11.2, R12.1
Q2C: C11.1, Q2.3 (C), R14.1
Q2E: Q2.2 (E), R13.1
SIG_IN: C7.1, J1.1, R10.1
SW: L1.2, U1.1 (SW)
T555: C21.1, R20.1, U2.6 (TH), U2.7 (DIS)
TH: R17.1, U3.2 (-)
TH_HI: R19.1, V2.1
TH_LO: R18.1, V2.3
TH_W: R17.2, V2.2 (W)
TTL_OUT: J2.1, U4.5 (OUT)
VADJ_HI: D1.1 (K), V1.3
VADJ_LO: R7.1, V1.1
VOUT40: C1.1, C2.1, C3.1, R3.1, U1.5 (CAP), U8.7 (V+)
VREF_B: CF7.1, D1.2 (A), U7.5 (OUT)
VREG38: R5.2, R8.1, U8.6
VSET: C4.1, R6.1, U8.3 (+), V1.2 (W)

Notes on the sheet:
SiPM (cavo Fileca)
Amplificatore front-end SiPM
Comparatore di soglia
Soglia (V2)
Rif. soglia 3,6V
TTL OUT
Driver uscita
Monostabile LED (~11ms)
Boost 40,2V (bias SiPM)
38,4V
regolazione tensione (V1)
Rif. 3,6V (B)
+5V IN
Alimentazione 5V -> 3,3V
Buffer uscita 3,3V -> Raspberry Pi (74LVC1G17)
LEMO
Riv. Cosmici 2024 - Amplif, alim, soglie - ricostruito da PDF INFN sez. Torino (S. Gallian, rev. A)

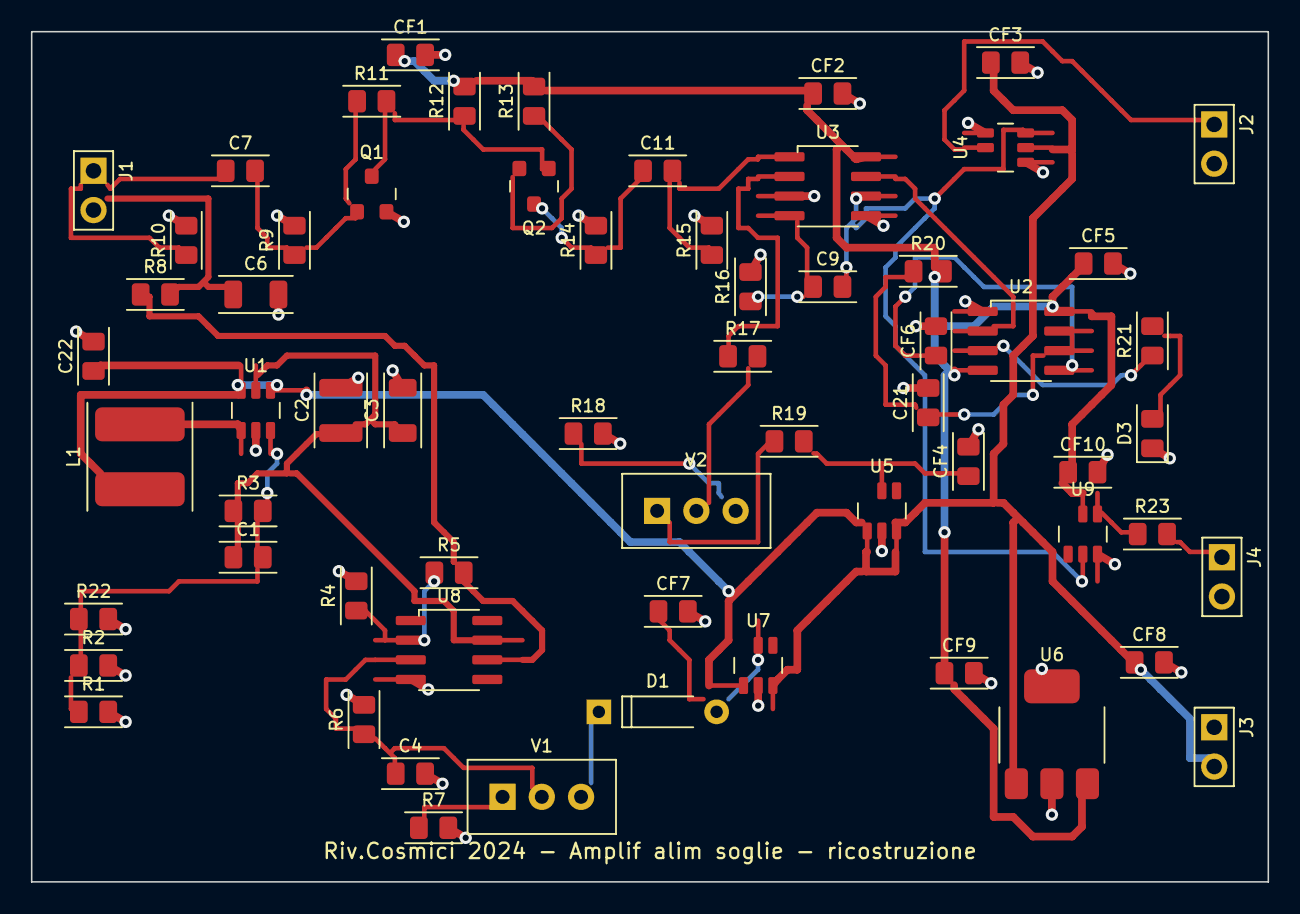
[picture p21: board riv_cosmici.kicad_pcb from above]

Board: 2 copper layers, 80.0 x 55.0 mm, 63 parts (0 on the bottom side), 34 nets.

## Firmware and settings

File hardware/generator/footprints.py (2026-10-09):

# -*- coding: utf-8 -*-
"""Footprint library 'rivlib' (formato KiCad 6 .kicad_mod).
Ogni footprint espone pads: {num: (x, y, w, h, kind)} con kind in
{'smd','tht','tht_rect'} per il generatore PCB e il DRC.
Convenzione: Y verso il basso (coordinate footprint KiCad).
"""

class FP:
    def __init__(self, name, pads, courtyard, silk=None, desc="", th_body=None):
        # pads: list of (num, x, y, w, h, kind, drill)
        self.name = name
        self.pads = {str(p[0]): p[1:] for p in pads}
        self.courtyard = courtyard  # (x1,y1,x2,y2)
        self.silk = silk or []      # list of line segs (x1,y1,x2,y2)
        self.desc = desc

    def sexpr(self):
        o = []
        o.append(f'(footprint "rivlib:{self.name}" (version 20211014) (generator rivgen) (layer "F.Cu")')
        o.append(f'  (attr smd)' if all(p[4] == "smd" for p in self.pads.values()) else '  (attr through_hole)')
        o.append(f'  (descr "{self.desc}")')
        o.append('  (fp_text reference "REF**" (at 0 -3.2) (layer "F.SilkS") (effects (font (size 0.8 0.8) (thickness 0.12))))')
        o.append('  (fp_text value "VAL**" (at 0 3.2) (layer "F.Fab") (effects (font (size 0.8 0.8) (thickness 0.12))))')
        x1, y1, x2, y2 = self.courtyard
        o.append(f'  (fp_rect (start {x1} {y1}) (end {x2} {y2}) (layer "F.CrtYd") (width 0.05) (fill none))')
        for (sx1, sy1, sx2, sy2) in self.silk:
            o.append(f'  (fp_line (start {sx1} {sy1}) (end {sx2} {sy2}) (layer "F.SilkS") (width 0.12))')
        for num, (x, y, w, h, kind, drill) in self.pads.items():
            num = num.split("#")[0]          # "2#3" = terzo pad del pin 2
            if kind == "smd":
                o.append(f'  (pad "{num}" smd roundrect (at {x} {y}) (size {w} {h}) '
                         f'(layers "F.Cu" "F.Paste" "F.Mask") (roundrect_rratio 0.2))')
            else:
                shape = "rect" if kind == "tht_rect" else "circle"
                o.append(f'  (pad "{num}" thru_hole {shape} (at {x} {y}) (size {w} {h}) '
                         f'(drill {drill}) (layers "*.Cu" "*.Mask"))')
        o.append(')')
        return "\n".join(o)

FPS = {}
def add(fp):
    FPS[fp.name] = fp

def chip2(name, px, w, h, cw, ch, desc):
    add(FP(name,
           [(1, -px, 0, w, h, "smd", 0), (2, px, 0, w, h, "smd", 0)],
           (-cw, -ch, cw, ch),
           silk=[(-cw, -ch, cw, -ch), (-cw, ch, cw, ch)],
           desc=desc))

chip2("R_0805", 0.95, 1.15, 1.45, 1.85, 1.0, "R 0805 (2012)")
chip2("C_0805", 0.95, 1.15, 1.45, 1.85, 1.0, "C 0805 (2012)")
chip2("C_1206", 1.4625, 1.15, 1.8, 2.4, 1.2, "C 1206 (3216)")
chip2("C_1210", 1.4625, 1.15, 2.8, 2.4, 1.7, "C 1210 (3225)")
add(FP("LED_0805",
       [(1, -0.95, 0, 1.15, 1.45, "smd", 0), (2, 0.95, 0, 1.15, 1.45, "smd", 0)],
       (-1.85, -1.0, 1.85, 1.0),
       silk=[(-1.85, -1.0, 1.85, -1.0), (-1.85, 1.0, 1.85, 1.0),
             (-1.85, -1.0, -1.85, 1.0)],   # barra lato catodo (pin 1)
       desc="LED 0805, pin1=K"))

# SOT-23: 1 SW-left(sud sx), 2 sud dx?? -> convenzione standard: 1,2 sud (y+), 3 nord
add(FP("SOT23",
       [(1, -0.95, 1.15, 0.9, 1.0, "smd", 0),
        (2, 0.95, 1.15, 0.9, 1.0, "smd", 0),
        (3, 0, -1.15, 0.9, 1.0, "smd", 0)],
       (-1.7, -1.9, 1.7, 1.9),
       silk=[(-1.55, -0.35, -1.55, 0.35), (1.55, -0.35, 1.55, 0.35)],
       desc="SOT-23 (1=B 2=E 3=C)"))

def sot23n(name, south, north, desc):
    pads = []
    for i, num in enumerate(south):
        pads.append((num, -0.95 + i * 0.95, 1.3, 0.6, 1.1, "smd", 0))
    for i, num in enumerate(north):
        pads.append((num, 0.95 - i * 0.95, -1.3, 0.6, 1.1, "smd", 0))
    add(FP(name, pads, (-1.7, -2.1, 1.7, 2.1),
           silk=[(-1.55, -0.5, -1.55, 0.5), (1.55, -0.5, 1.55, 0.5)],
           desc=desc))

sot23n("SOT23-5", ["1", "2", "3"], ["4", "5"], "SOT-23-5 (pin1 sud-sx)")
sot23n("SOT23-6", ["1", "2", "3"], ["4", "5", "6"], "SOT-23-6 / ThinSOT")

# SOIC-8: pin1 in alto a sinistra, colonna sx 1-4 (y -1.905..1.905), dx 8-5
_soic = []
for i in range(4):
    _soic.append((str(i + 1), -2.475, -1.905 + i * 1.27, 1.95, 0.6, "smd", 0))
for i in range(4):
    _soic.append((str(8 - i), 2.475, -1.905 + i * 1.27, 1.95, 0.6, "smd", 0))
add(FP("SOIC8", _soic, (-3.7, -2.7, 3.7, 2.7),
       silk=[(-1.95, -2.6, 1.95, -2.6), (-1.95, 2.6, 1.95, 2.6),
             (-1.95, -2.6, -1.95, -2.2)],  # tacca lato pin1
       desc="SOIC-8 3.9x4.9 P1.27"))

# SOIC-14 (MCP3424): pin1 in alto a sinistra, colonna sx 1-7, dx 14-8
_soic14 = []
for i in range(7):
    _soic14.append((str(i + 1), -2.475, -3.81 + i * 1.27, 1.95, 0.6, "smd", 0))
for i in range(7):
    _soic14.append((str(14 - i), 2.475, -3.81 + i * 1.27, 1.95, 0.6, "smd", 0))
add(FP("SOIC14", _soic14, (-3.7, -4.6, 3.7, 4.6),
       silk=[(-1.95, -4.45, 1.95, -4.45), (-1.95, 4.45, 1.95, 4.45),
             (-1.95, -4.45, -1.95, -4.05)],
       desc="SOIC-14 3.9x8.65 P1.27"))

# SOT-223 (tab = pad 4): pin 1,2,3 sud, tab nord
add(FP("SOT223",
       [(1, -2.3, 3.15, 1.5, 2.0, "smd", 0),
        (2, 0, 3.15, 1.5, 2.0, "smd", 0),
        (3, 2.3, 3.15, 1.5, 2.0, "smd", 0),
        (4, 0, -3.15, 3.6, 2.2, "smd", 0)],
       (-3.85, -4.4, 3.85, 4.4),
       silk=[(-3.4, -1.8, -3.4, 1.8), (3.4, -1.8, 3.4, 1.8)],
       desc="SOT-223-3, tab=pad4"))

# 1N4148 DO-35 orizzontale passo 7.62, pin1 = K (banda)
add(FP("D_DO35",
       [(1, -3.81, 0, 1.6, 1.6, "tht_rect", 0.8),
        (2, 3.81, 0, 1.6, 1.6, "tht", 0.8)],
       (-4.8, -1.2, 4.8, 1.2),
       silk=[(-2.3, -1.0, 2.3, -1.0), (-2.3, 1.0, 2.3, 1.0),
             (-2.3, -1.0, -2.3, 1.0), (-1.7, -1.0, -1.7, 1.0)],
       desc="DO-35 P7.62, pin1=K"))

# Trimmer Bourns 3296W: 3 fori in linea passo 2.54 (1 CCW, 2 wiper, 3 CW)
add(FP("TRIM_3296W",
       [(1, -2.54, 0, 1.7, 1.7, "tht_rect", 0.9),
        (2, 0, 0, 1.7, 1.7, "tht", 0.9),
        (3, 2.54, 0, 1.7, 1.7, "tht", 0.9)],
       (-4.9, -2.5, 4.9, 2.5),
       silk=[(-4.8, -2.4, 4.8, -2.4), (-4.8, 2.4, 4.8, 2.4),
             (-4.8, -2.4, -4.8, 2.4), (4.8, -2.4, 4.8, 2.4)],
       desc="Bourns 3296W 3/8in trimmer, inline P2.54"))

# Header 2.54 1x2 verticale
add(FP("HDR1x02",
       [(1, 0, 0, 1.7, 1.7, "tht_rect", 1.0),
        (2, 2.54, 0, 1.7, 1.7, "tht", 1.0)],
       (-1.3, -1.3, 3.85, 1.3),
       silk=[(-1.27, -1.27, 3.81, -1.27), (-1.27, 1.27, 3.81, 1.27),
             (-1.27, -1.27, -1.27, 1.27), (3.81, -1.27, 3.81, 1.27)],
       desc="Pin header 2.54 1x2"))

# Molex KK 254 2 poli, header verticale con rampa di aggancio (22-27-2021):
# stessi fori della strip 1x2, corpo piu' profondo (~6 mm) con la rampa sul lato y+
add(FP("MOLEX_KK_2",
       [(1, 0, 0, 1.7, 1.7, "tht_rect", 1.0),
        (2, 2.54, 0, 1.7, 1.7, "tht", 1.0)],
       (-2.0, -3.2, 4.55, 3.2),
       silk=[(-1.8, -2.95, 4.34, -2.95), (-1.8, 2.95, 4.34, 2.95),
             (-1.8, -2.95, -1.8, 2.95), (4.34, -2.95, 4.34, 2.95),
             (-1.3, 2.3, 3.84, 2.3)],                     # rampa di aggancio
       desc="Molex KK 254 22-27-2021, 2 poli, verticale con aggancio"))

# Header 2.54 1x3 verticale (connettore I2C verso il Raspberry Pi)
add(FP("HDR1x03",
       [(1, 0, 0, 1.7, 1.7, "tht_rect", 1.0),
        (2, 2.54, 0, 1.7, 1.7, "tht", 1.0),
        (3, 5.08, 0, 1.7, 1.7, "tht", 1.0)],
       (-1.3, -1.3, 6.4, 1.3),
       silk=[(-1.27, -1.27, 6.35, -1.27), (-1.27, 1.27, 6.35, 1.27),
             (-1.27, -1.27, -1.27, 1.27), (6.35, -1.27, 6.35, 1.27)],
       desc="Pin header 2.54 1x3"))

# Foro di fissaggio M3: foro 3,2 mm metallizzato, piazzola 6 mm (a massa)
add(FP("MH_M3",
       [(1, 0, 0, 6.0, 6.0, "tht", 3.2)],
       (-3.5, -3.5, 3.5, 3.5),
       desc="Foro di fissaggio M3 metallizzato"))

# Test point per sonda d'oscilloscopio: foro 1,0 mm (anello Keystone 5001/5000
# o un filo piegato ad anello), pad 2,0 mm
add(FP("TP_THT",
       [(1, 0, 0, 2.0, 2.0, "tht", 1.0)],
       (-1.3, -1.3, 1.3, 1.3),
       desc="Test point THT, foro 1.0 mm"))

# LEMO serie 00, presa a gomito da circuito stampato EPL.00.250.NTN:
# contatto centrale + 4 piedini di schermo su quadrato 5,08 mm, fori 0,8 mm.
# Il frontale guarda verso +X: piazzare con X del centro a ~4 mm dal bordo
# scheda; il corpo (L = 17,5 mm) sporge oltre il bordo. Courtyard solo sulla
# parte sopra la scheda.
add(FP("LEMO_EPL00",
       [(1, 0, 0, 1.5, 1.5, "tht", 0.8),
        ("2", -2.54, -2.54, 1.5, 1.5, "tht", 0.8), ("2#2", 2.54, -2.54, 1.5, 1.5, "tht", 0.8),
        ("2#3", -2.54, 2.54, 1.5, 1.5, "tht", 0.8), ("2#4", 2.54, 2.54, 1.5, 1.5, "tht", 0.8)],
       (-3.8, -3.8, 4.0, 3.8),
       silk=[(-3.5, -3.5, 4.0, -3.5), (-3.5, 3.5, 4.0, 3.5), (-3.5, -3.5, -3.5, 3.5)],
       desc="LEMO EPL.00.250.NTN gomito, 00 serie (frontale verso +X)"))

# Induttore di potenza 5x5 (SRN5040 e simili)
add(FP("L_PWR_5050",
       [(1, -2.1, 0, 2.2, 5.8, "smd", 0), (2, 2.1, 0, 2.2, 5.8, "smd", 0)],
       (-3.6, -3.5, 3.6, 3.5),
       silk=[(-3.5, -3.4, 3.5, -3.4), (-3.5, 3.4, 3.5, 3.4)],
       desc="Power inductor SMD 5x5/6x6 (SRN5040/SRR6040) - verificare vs parte RS 6934344"))

def write_lib(dirname):
    import os
    os.makedirs(dirname, exist_ok=True)
    for fp in FPS.values():
        with open(os.path.join(dirname, fp.name + ".kicad_mod"), "w") as f:
            f.write(fp.sexpr() + "\n")
    print(f"scritti {len(FPS)} footprint in {dirname}")

if __name__ == "__main__":
    write_lib("riv_cosmici/rivlib.pretty")

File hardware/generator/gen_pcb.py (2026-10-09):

# -*- coding: utf-8 -*-
"""Genera riv_cosmici.kicad_pcb: piazzamento, escape GND con via,
autorouter a griglia (F.Cu preferito, B.Cu con via), pour GND su B.Cu,
DRC geometrico e verifica connettivita'.
"""
import math, heapq, re, uuid
from shapely.geometry import box, Point, LineString, MultiPolygon, Polygon
from shapely.ops import unary_union
from shapely.prepared import prep
import shapely.affinity as aff

from pcb_data import (BOARD, PLACEMENT, COMPONENTS, FP_OF, abs_pads, pad_rect,
                      track_w, CLEARANCE, HV_NETS, HV_CLEAR)
from footprints import FPS
from netdata import NETS

X1, Y1, X2, Y2 = BOARD
GRID = 0.635
VIA_D, VIA_DRILL = 0.8, 0.4
EDGE_CLR = 0.4

pads = abs_pads()
tracks = []   # dict: net, layer, pts [(x,y)..], w
vias = []     # dict: net, x, y

# ---------------- courtyard overlap check ----------------
def courtyards():
    out = []
    for ref, (x, y, rot) in PLACEMENT.items():
        fp = FPS[FP_OF[COMPONENTS[ref][2]]]
        cx1, cy1, cx2, cy2 = fp.courtyard
        b = box(cx1, cy1, cx2, cy2)
        b = aff.rotate(b, -rot, origin=(0, 0))
        b = aff.translate(b, x, y)
        out.append((ref, b))
    return out

def check_courtyards():
    cts = courtyards()
    bad = []
    brd = box(X1, Y1, X2, Y2)
    for i in range(len(cts)):
        if not brd.contains(cts[i][1]):
            bad.append((cts[i][0], "fuori scheda"))
        for j in range(i + 1, len(cts)):
            if cts[i][1].intersects(cts[j][1]):
                a = cts[i][1].intersection(cts[j][1]).area
                if a > 0.01:
                    bad.append((cts[i][0], cts[j][0], round(a, 2)))
    return bad

# ---------------- GND escape vias ----------------
def add_gnd_vias():
    """per ogni pad SMD GND: stub + via verso il pour B.Cu (scelta del punto migliore)."""
    for p in pads:
        if p["net"] != "GND" or p["kind"] != "smd":
            continue
        best = None
        for ang in range(0, 360, 30):
            for dist in (1.3, 1.6, 2.0, 2.4):
                vx = round(p["x"] + dist * math.cos(math.radians(ang)), 3)
                vy = round(p["y"] + dist * math.sin(math.radians(ang)), 3)
                if not (X1 + 1 < vx < X2 - 1 and Y1 + 1 < vy < Y2 - 1):
                    continue
                vgeo = Point(vx, vy).buffer(VIA_D / 2 + CLEARANCE + 0.12)
                stub = LineString([(p["x"], p["y"]), (vx, vy)]).buffer(track_w("GND") / 2 + CLEARANCE + 0.12)
                score = 9e9
                ok = True
                for q in pads:
                    if q is p or q["net"] == "GND":
                        continue
                    qr = pad_rect(q)
                    d = min(qr.distance(vgeo), qr.distance(stub))
                    if qr.intersects(vgeo) or qr.intersects(stub):
                        ok = False; break
                    score = min(score, d)
                if not ok:
                    continue
                for t in tracks:
                    if t["net"] == "GND":
                        continue
                    tg = LineString(t["pts"]).buffer(t["w"] / 2)
                    if tg.intersects(vgeo) or tg.intersects(stub):
                        ok = False; break
                    score = min(score, min(tg.distance(vgeo), tg.distance(stub)))
                if not ok:
                    continue
                for v in vias:
                    if (v["x"] - vx) ** 2 + (v["y"] - vy) ** 2 < (VIA_D + CLEARANCE) ** 2:
                        ok = False; break
                if not ok:
                    continue
                score -= dist * 0.05   # preferisci via vicine
                if best is None or score > best[0]:
                    best = (score, vx, vy)
        if best is None:
            print("!! niente via GND per", p["ref"], p["pin"])
            continue
        _, vx, vy = best
        vias.append(dict(net="GND", x=vx, y=vy))
        tracks.append(dict(net="GND", layer="F.Cu",
                           pts=[(p["x"], p["y"]), (vx, vy)], w=track_w("GND")))

# ---------------- escape stubs (fanout) ----------------
STUBS = {}   # (ref,pin) -> (end_x, end_y)
STUB_DIR_OVERRIDE = {("U1", "4"): (1, 0), ("U7", "1"): (-1, 0)}   # direzione locale forzata
def add_escape_stubs():
    from pcb_data import rot_delta
    for p in pads:
        if p["kind"] != "smd" or p["net"] is None or min(p["w"], p["h"]) >= 0.8:
            continue
        # direzione locale dominante (via dal corpo), poi ruotata
        fpk = COMPONENTS[p["ref"]][2]
        fp = FPS[FP_OF[fpk]]
        px, py, w0, h0, k0, dr0 = fp.pads[p["pin"]]
        if (p["ref"], p["pin"]) in STUB_DIR_OVERRIDE:
            dloc = STUB_DIR_OVERRIDE[(p["ref"], p["pin"])]
            half = (w0 if dloc[0] else h0) / 2 + 0.6
        elif w0 > h0 + 0.2 or (abs(w0 - h0) <= 0.2 and abs(px) >= abs(py)):
            # pad allungato in x (es. SOIC): esce di lato, anche per i pin d'angolo
            dloc = (1 if px > 0 else -1, 0); half = w0 / 2
        else:
            dloc = (0, 1 if py > 0 else -1); half = h0 / 2
        rot = PLACEMENT[p["ref"]][2]
        dx, dy = rot_delta(dloc[0], dloc[1], rot)
        ln = half + 0.8
        ex, ey = p["x"] + dx * ln, p["y"] + dy * ln
        # snap dell'estremo sulla griglia del router (nella direzione di uscita)
        import math as _m
        if abs(dx) > 0.5:
            k = (ex - X1) / GRID
            ex = X1 + (_m.ceil(k) if dx > 0 else _m.floor(k)) * GRID
        if abs(dy) > 0.5:
            k = (ey - Y1) / GRID
            ey = Y1 + (_m.ceil(k) if dy > 0 else _m.floor(k)) * GRID
        ex, ey = round(ex, 3), round(ey, 3)
        tracks.append(dict(net=p["net"], layer="F.Cu",
                           pts=[(p["x"], p["y"]), (ex, ey)], w=0.3))
        STUBS[(p["ref"], p["pin"])] = (ex, ey)

# ---------------- router ----------------
def net_pads(net):
    return [p for p in pads if p["net"] == net]

def geo_of_tracks(net, layer):
    gg = []
    for t in tracks:
        if t["net"] == net and t["layer"] == layer:
            gg.append(LineString(t["pts"]).buffer(t["w"] / 2))
    return gg

DIAG_MARGIN = 0.22

def raw_metal(net):
    """metallo reale altrui per layer (senza buffer)."""
    out = {"F.Cu": [], "B.Cu": []}
    for p in pads:
        if p["net"] == net:
            continue
        g = pad_rect(p)
        if p["kind"] == "smd":
            out["F.Cu"].append(g)
        else:
            out["F.Cu"].append(g); out["B.Cu"].append(g)
    for t in tracks:
        if t["net"] == net:
            continue
        out[t["layer"]].append(LineString(t["pts"]).buffer(t["w"] / 2))
    for v in vias:
        if v["net"] == net:
            continue
        g = Point(v["x"], v["y"]).buffer(VIA_D / 2)
        out["F.Cu"].append(g); out["B.Cu"].append(g)
    return {L: unary_union(gs) if gs else None for L, gs in out.items()}
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

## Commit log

2026-07-17 Rivelatore di raggi cosmici: hardware KiCad, buffer, simulazioni, verifica dallo schema, sito e firmware
    - schema/PCB/Gerber/BOM ricostruiti dal PDF INFN 'Riv. Cosmici 2024'
    - buffer d'uscita 2x MMBT2222A verso Arduino (da CMP_Q, 5V, connettore LEMO/J4)
    - simulazioni circuitali non lineari (catena, muoni, buffer, end-to-end)
    - estrattore di netlist dal .kicad_sch + verifica che gira dallo schema
    - sito didattico interattivo (schematico vivo) e firmware Arduino
    - licenza CERN-OHL-W-2.0
    [BOM_riv_cosmici.csv, BOM_riv_cosmici.xlsx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]
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2026-10-09 Scheda completa: simulazione LTspice, correzione V2, uscita 3,3 V per Raspberry Pi
    - Schema KiCad confrontato pin per pin con l'originale INFN: V2 e' un
    potenziometro (cursore -> R17 -> TH), non un reostato. Corretto.
    - Uscita J4 per Raspberry Pi: il buffer a 2 transistor a 5 V (lento,
    uscita fino a -0,7 V, 5 V sui GPIO) sostituito da U9 74LVC1G17 a +3V3
    + R23 33 ohm. Buffer ora anche su PCB e Gerber.
    - PCB rigenerato (autorouter con rip-up & retry): 0 errori DRC e
    connettivita'. Gerber + zip, anteprime, riv.kicad_sym, BOM generata
    da netdata.py (gen_bom.py).
    - simulation/ltspice/: scheda intera come schema LTspice (.asc + .asy)
    e netlist (.cir), generati dallo stesso modello dat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
    [BOM_riv_cosmici.csv, BOM_riv_cosmici.xlsx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]
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2026-10-09 File per l'ordine JLCPCB (Gerber, BOM, CPL) e guida al modulo d'ordine
    - gen_jlcpcb.py: BOM e CPL nel formato JLCPCB dal modello dati; U1, U3, U8
    esclusi (DNP, saldati a mano); codici LCSC dove verificati, MPN di
    riferimento per gli altri; TLC555CDR al posto di LMC555CM (in dismissione).
    - hardware/jlcpcb/LEGGIMI.md: opzioni PCB e PCBA, controlli sui componenti
    e sulle rotazioni, varianti consigliate, parti da comprare a parte.
    - PRIMA_DI_ORDINARE.md: sequenza di prima accensione a stadi.
    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
    [BOM_JLCPCB.csv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]
2026-10-09 JLCPCB: BOM/CPL anche in xlsx col modello minimo, guida al caricamento
    Claude-Session: https://claude.ai/code/session_017fc9yPsNewCQrMK8R1c8Ls
    [BOM_JLCPCB.csv, BOM_JLCPCB.xlsx, MPN_riferimento.csv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]
2026-10-09 JLCPCB: colonna "JLCPCB Part #", codici esatti, U5/U7/D1/J1-J4 a mano
    Dal report del BOM Tool di JLCPCB: la colonna "LCSC Part #" veniva ignorata
    e i resistori abbinati a caso. Ora ogni riga ha il codice JLCPCB o l'MPN
    (resistori UNI-ROYAL 0805W8F...T5E). LP2985-3.6 e 1N4148 esauriti e header
    non riconosciuti passano alla lista da saldare a mano.
    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
    [BOM_JLCPCB.csv, BOM_JLCPCB.xlsx, MPN_riferimento.csv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]
2026-10-09 Variante 3 canali (schema), render 3D, anteprima schema corretta
    - netdata3/gen_sch3: scheda a 3 canali generata dal modello a 1 canale
    (canali replicati, parti comuni una volta), coincidenza 74LVC1G11 con
    jumper di esclusione, uscite LEMO 00, test point per oscilloscopio.
    Schema verificato rileggendo il .kicad_sch (0 reti diverse).
    - footprint LEMO EPL.00.250.NTN, test point, simboli TP e LVC1G11 (anche
    in riv.kicad_sym e rivlib.pretty); piu' pad con lo stesso numero.
    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
    [riv_cosmici.kicad_sch]
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2026-10-09 Variante 3 canali: test point lungo il bordo destro; il router riprova anche su errori DRC/connettivita'
    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
    [gen_pcb.py, pcb_data3.py]
2026-10-09 Variante a 3 canali completa: PCB, Gerber, JLCPCB, render 3D; schemi in PDF
    - variante_3ch/: progetto KiCad (schema A1 + PCB 80x165 mm instradato,
    0 errori DRC/connettivita'), Gerber + zip, anteprima, BOM completa,
    BOM/CPL JLCPCB (131 montati, 47 a mano: chip critici, LEMO, test point,
    jumper), LEGGIMI con uscite, jumper, test point, montaggio.
    - render3d: ambiente "da studio" per i metalli (LEMO cromati), vista
    dall'alto inquadrata per schede lunghe, viste coincidenza e LEMO.
    - make_pdf.py: schemi vettoriali a grandezza reale (A3 e A1) con cartiglio
    in docs/ (anche uniti in schemi_riv_cosmici.pdf).
    Claude-Session: https://cl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
    [BOM_JLCPCB.csv, BOM_JLCPCB.xlsx, BOM_riv_cosmici_3ch.csv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]
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2026-10-09 Variante 3ch: PCB didattico rifatto a blocchi, test point accanto ai nodi
    - piazzamento a fasce: alimentazione, 3 canali identici (segnale in alto
    da sinistra a destra, circuiti di supporto sotto), coincidenza in basso
    - test point a pochi mm dal nodo misurato (SIG_IN 94 -> 9 mm di pista)
    - uscite verso la coincidenza in un corridoio riservato sul bordo destro
    - serigrafia didattica (silk3.py): blocchi numerati, titoli, etichette dei
    test point e dei connettori, riferimenti, schema a blocchi, legenda
    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
    [BOM_JLCPCB.xlsx, BOM_riv_cosmici_3ch.csv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]
2026-10-09 Variante 3ch: tolto il cartiglio, SURVOLTORE -> ALTA TENSIONE in serigrafia
    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
    [BOM_JLCPCB.xlsx, riv_cosmici_3ch.kicad_pcb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]
2026-10-09 Variante 3ch: BOM Farnell corretta e snellita, progetto KiCad in zip
    - LT1636: il codice 4020771 era la versione MSOP (CMS8): ora per MPN LT1636CS8#PBF
    - 1N4148: 3606680 era una bobina da 5000 pezzi (24 settimane) -> 2889103 a pezzi
    - test point con pin di strip header al posto dei Keystone (niente spedizione dagli USA)
    - scorte MAX961/LT1636 da 17 a 16
    - riv_cosmici_3ch_kicad.zip: .kicad_pro/.kicad_sch/.kicad_pcb + librerie
    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
    [BOM_JLCPCB.xlsx, BOM_farnell.csv, BOM_farnell.xlsx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]
2026-10-09 Variante 3ch: BOM Farnell e Mouser in CSV (abbinamento per MPN)
    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
    [BOM_farnell.csv, BOM_mouser.csv]
2026-10-09 Pitch PowerPoint con budget e preventivi; render Keystone e PCB nero
    - render3d: maschera nera (scene.py 3ch nero, ?pcb=nero), sfondo (?bg=),
    viste ravvicinate dei test point (tp, tp2)
    - docs/pitch: presentazione di 12 slide (pptx + pdf) e script che la genera
    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
2026-10-09 Variante 3ch: monitor delle tensioni dei SiPM (ADC MCP3424 in I2C)
    - partitori 1M/43k + 100n su VREG38 di ogni canale e sull'alta tensione
    - ADC MCP3424 (U11, 0x68), resistenze serie 100R su SDA/SCL, connettore J6
    - router: le linee MON stanno a >= 1,2 mm dai nodi analogici sensibili su
    entrambi gli strati (misurato: 1,6 mm); piste dei segnali invariate
    - simulazione: con il monitor bias, impulsi e soglia restano identici
    - software/monitor_tensioni.py per il Raspberry Pi
    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
    [BOM_JLCPCB.csv, BOM_JLCPCB.xlsx, BOM_farnell.csv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]
2026-10-09 Variante 3ch: disposizione piu' ordinata e fori di fissaggio M3
    - scheda 103 x 215 mm: colonne distanziate (>= 2 mm tra i riquadri), spostamenti
    multipli della griglia del router
    - serigrafia: riquadri della stessa riga con bordi allineati, titoli fissi,
    sottotitoli sotto il riquadro, frecce del segnale calcolate tra i blocchi,
    avviso 41 V nel blocco ALTA TENSIONE
    - 8 fori M3 metallizzati a massa (angoli e confini tra i canali)
    - routing rifatto: 0 errori DRC/connettivita', monitor a 1,6 mm dai nodi sensibili
    - render, PDF, presentazione aggiornati
    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
    [BOM_JLCPCB.xlsx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]
2026-10-09 Piano per due prototipi da laboratorio: lista Mouser ridotta, budget minimo
    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
    [BOM_mouser_2prototipi.csv]
2026-10-09 Prototipi: connettore Molex KK 254 tra cavo della barra e scheda (bias sulla calza)
    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
    [BOM_mouser_2prototipi.csv]
2026-10-09 Connettori Molex KK 254 per i cavi delle barre anche nella documentazione e nella BOM Mouser
    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
    [BOM_mouser.csv]
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
